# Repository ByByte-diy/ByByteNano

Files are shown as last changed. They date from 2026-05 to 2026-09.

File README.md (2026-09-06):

## **ByByte.DIY™ Nano** — Educational Robot Platform





Українська: [`README.uk`](README.uk.md)

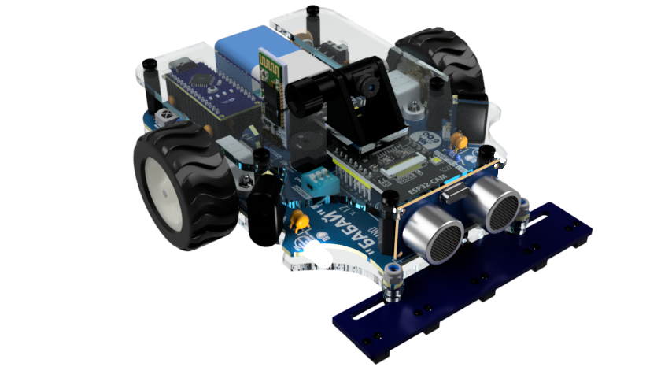
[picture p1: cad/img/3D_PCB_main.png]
ByByte Nano 3D View


**ByByte Nano** is a compact, beginner‑friendly educational robot platform from the ByByte series. It is designed for quick assembly, safe classroom use, and clear learning of robotics fundamentals: electronics, sensors, motor control, and embedded programming. Compared to the more advanced ByByte Mega, Nano focuses on simplicity and affordability while remaining extendable.

- Related project: see the larger sibling, ByByte Mega, for a more feature‑rich variant ([ByByte Mega](https://github.com/ByByte-diy/ByByteMega/blob/main/README.md)).

### Key Features
- Beginner‑friendly: simple assembly and clear layout
- Compact PCB: optimized footprint for classrooms and workshops
- Modular design: expansion headers for add‑ons and sensors
- Open hardware: schematic and PCB sources included
- Open firmware: works with common Arduino‑compatible toolchains

### Hardware Overview
- Main board: ByByte Nano PCB
- Microcontroller: Arduino‑compatible, Nano‑class form factor (ATmega328)
- Typical peripherals: motor drivers, line sensors, LEDs, power regulation
- Connectors: clearly labeled I/O and power headers for quick prototyping

View the full schematic:
- [`Schematic (PDF)`](hardware/schematics/SCH_ByByte_nano.pdf)

Board previews:
- [`Top PCB`](cad/img/2D_pcb_top.png)
- [`Bottom PCB`](cad/img/2D_pcb_bottom.png)

### Technical Specifications (high‑level)
- Power: 9V battery (PP3/“Krona”)
- CPU: Arduino Nano (ATmega328)
- Drive: micro N20 geared DC motors, approx. 600–1000 rpm
- Connectivity: USB (Arduino Nano), Bluetooth (HC‑02/HC‑05/HC‑06), optional Wi‑Fi via ESP32‑CAM

### Sensors and Interfaces
- 5 line sensors: line‑following capability
- Side optical analog sensors: maze navigation or obstacle avoidance
- Front distance sensor: ultrasonic range measurement
- Analog light sensor: ambient light intensity
- IR receiver: remote control via IR remote
- Bluetooth: smartphone/PC control support
- 2× WS2812 RGB LEDs: “headlights” visual feedback
- Passive buzzer: audible feedback

### Additional Peripherals
You can install an optional ESP32‑CAM module to stream video over Wi‑Fi. The ESP module can be programmed directly from the robot; set jumpers J1–J3 according to the schematic. You can also configure communication between ESP and the Arduino Nano to control the robot over Wi‑Fi.

### Mobility
Two side wheels provide differential (tank‑style) drive for precise motion control.

### Compatibility
Fully compatible with the Arduino IDE and a wide range of Arduino libraries, making it accessible for both beginners and experienced users.

### Educational Focus
Designed to help learners develop core programming and robotics skills through hands‑on projects:
- Integrate sensors and process data
- Program motion algorithms for obstacle avoidance, line following, and maze navigation
- Use visual and audio feedback to increase interactivity
- Understand controller‑based platforms and communication/control basics

### Assembly Notes
- Besides the PCB and ready‑made modules, a few discrete components are needed for assembly; the design targets easy soldering and widely available modules
- Before soldering the robot’s power modules, set the correct output voltages (5 V and 3.3 V) to protect sensitive electronics
- Before first power‑up, verify polarity; ideally power on without modules inserted and check all rails
- Start with power and logic tests, then connect motors and sensors
- Keep wires short and secure to reduce noise
- Finally, test the robot with example sketches before full use

### Bill of Materials

The complete parts list — **55 line items** with designators, quantities, values, and component photos — is in **[BOM.md](BOM.md)**.

At a glance, the build includes the ByByte Nano PCB, Arduino Nano, motor driver (DRV8834), N20 geared motors with wheels and mounts, 5-channel line tracker, ultrasonic sensor, Bluetooth module (HC-02/HC-05/HC-06), two DC-DC buck modules, ESP32-CAM (optional), and assorted passives, connectors, and mechanical hardware.

### Troubleshooting
- No power: check polarity and regulator output
- No USB upload: check board/port selection, drivers, and jumper positions J1–J3
- Motors not spinning: verify driver wiring and module health
- Sensors unresponsive: verify 5 V rail and wiring

### How to Contribute
Contributions are welcome:
1. Test and report issues by creating an issue
2. Help us fix problems and improve documentation
3. Optimize or enhance libraries by forking the repo and submitting a pull request

### License
This project is released under the license specified in [`LICENSE`](LICENSE.md).

This project is part of the ByByte.DIY™ open robotics ecosystem.

### Trademark notice:
**ByByte.DIY™** and the ByByte.DIY **logo** are trademarks of the project maintainers.

Copyright ⓒ 2026 ByByte.DIY™ contributors

<picture>
  <source media="(prefers-color-scheme: dark)" srcset="https://home.cern/wp-content/themes/cern/public/images/logo-white.svg">
  <source media="(prefers-color-scheme: light)" srcset="https://home.cern/wp-content/themes/cern/public/images/logo-blue.svg">
  CERN
</picture>

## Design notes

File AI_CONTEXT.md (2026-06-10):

# AI_CONTEXT.md — ByByte Nano (LLM / RAG Context)

> **Purpose:** structured technical context for the `ByByte-diy/ByByteNano` repository, intended for large language models, RAG pipelines, and coding agents.  
> **Project version:** 1.1.0 · **License:** CERN-OHL-S v2 · **Ecosystem:** ByByte.DIY™  
> **Last context sync:** 2026 (aligned with `README.md`, `BOM.md`, `hardware/`, `source/ByByte_nano.epro`)

---

## 1. Project Summary

**ByByte Nano** (also known as *Babai Nano* / *Бабай Nano* in Ukrainian materials) is a compact **open-hardware educational robotics platform**. It is designed for teaching electronics, sensors, motor control, and embedded programming in classrooms and workshops.

Key properties:
- beginner-friendly assembly (through-hole soldering + off-the-shelf modules);
- main controller: **Arduino Nano (ATmega328)**;
- differential drive (2× N20 geared motors);
- built-in sensor set: line tracking, distance, ambient light, IR remote;
- optional side IR sensors (mainly for maze navigation — may be omitted if not needed);
- optional **ESP32-CAM** (Wi-Fi / video);
- Bluetooth (**HC-02 / HC-05 / HC-06**);
- 2.54 mm expansion headers.

**Related platform:** [ByByte Mega](https://github.com/ByByte-diy/ByByteMega) — a more feature-rich sibling in the same product line.

**What this repository contains today:** hardware documentation, BOM, schematic, Gerber files, CAD images, and an EasyEDA project. **Firmware and example sketches are not included** in the repo (mentioned in README as external / planned).

---

## 2. Repository Map (Key Files)

| Path | Description |
|---|---|
| `README.md` / `README.uk.md` | Project overview (English / Ukrainian) |
| `BOM.md` | Full bill of materials (57 line items + consumables + tools) |
| `AI_CONTEXT.md` | This file — AI / RAG context |
| `LICENSE.md` / `LICENSE-CERN.txt` | CERN-OHL-S v2 |
| `hardware/schematics/SCH_ByByte_nano.pdf` | Schematic (PDF) |
| `hardware/pcb/ByByte_nano_pcb.pdf` | PCB layout preview (PDF) |
| `hardware/pcb/Gerber_pcb_ByByte_nano.zip` | Gerber package for PCB fabrication |
| `hardware/bom/BOM_ByByte_Nano.xlsx` | BOM spreadsheet |
| `hardware/bom/img/` | Component photos / renders |
| `cad/img/3D_PCB_main.png` | 3D board render |
| `cad/img/2D_pcb_top.png` | Top view (2D) — note lowercase `pcb` in filename |
| `cad/img/2D_pcb_bottom.png` | Bottom view (2D) |
| `source/ByByte_nano.epro` | EasyEDA project (ZIP archive: schematic + PCB) |

---

## 3. System Architecture (Functional Blocks)

On the main schematic (`main` sheet in EasyEDA), the board is organized into these logical blocks:

| Block (schematic label) | Function | Key components |
|---|---|---|
| **POWER SUPPLY** | 9V input, regulation | `BAT1`, `D4`, `D5`, `F1`, `U3`, `U4`, `C1–C5`, `L1`, `L2` |
| **CONTROLLER** | Main MCU | `U1` Arduino Nano |
| **MOTOR DRIVER** | N20 motor control | `U2` DRV8833, `M1`, `M2` |
| **ULTRASONIC** | Front ranging | `U5` HC-SR04 |
| **IR LINE TRACKER** | 5-channel line sensing | `U6` TRCT5000 5-way module |
| **SIDES SENSORS** *(optional)* | Side analog IR — maze navigation | `D1`, `D2`, `Q2`, `Q3`, `U9` LM358 |
| **IR SENSOR** | IR remote receiver | `U7` VS1838B |
| **LIGHT SENSOR** | Ambient light | `LDR1` + divider |
| **LEDS** | Status / headlights | `LED1` (green), `LED2`, `LED3` WS2812 |
| **BUZZER** | Audio feedback | `BUZZER1` |
| **BLUETOOTH** | Wireless control | `BLUETOOTH1` |
| **ESP32 Camera module** | Wi-Fi / camera (optional) | `U8` ESP32-CAM |

The EasyEDA project also includes a separate **`LineTracker_SCH`** schematic and **`LIneTracker_PCB`** — a reference line-tracker design. The assembled robot uses the ready-made module `U6` instead.

---

## 4. Power System

| Parameter | Value |
|---|---|
| Source | 9V Li-ion rechargeable battery, PP3 / “Krona” form factor (`BAT1` + BH9VPC holder) |
| Input protection | `F1` fuse (optional), ferrite beads `L1`, `L2` |
| Diodes | `D4` 1N5822, `D5` 1N5817 (Schottky) |
| Regulators | 2× DC-DC buck modules `U3`, `U4`: **MH-MINI-361** or **HW-613** (EasyEDA schematic lists MH-MINI-360) |
| Output rails | **+5 V** and **+3.3 V** (adjusted via trim pots on modules **before soldering!**) |
| Power switch | `SW1` slider switch |
| Indicator | `LED1` green — power (labeled PWR on schematic) |

**Critical assembly step:** before soldering `U3`/`U4`, use a multimeter to set **5.0 V** and **3.3 V**. On first power-up, test without plug-in modules installed; verify polarity and all rails.

---

## 5. Controller and Connectivity

### 5.1 Arduino Nano (`U1`)
- **MCU:** ATmega328, Arduino Nano form factor (v3, “old” footprint per BOM);
- mounted on **2× 1×15 female headers** (`U1 holder`, PBS-15);
- firmware upload via **USB** (Mini-B / Micro-B / Type-C depending on Nano revision);
- toolchain: **Arduino IDE**, standard Arduino libraries.

### 5.2 Bluetooth (`BLUETOOTH1`)
- Supported modules: **HC-02, HC-05, HC-06** (BOM lists HC-06);
- UART interface to Nano;
- control from smartphone or PC.

### 5.3 ESP32-CAM (`U8`, optional)
- Module with 120° camera;
- socket: **2× 1×8 female headers** (`U8 holder`);
- jumpers **J1, J2, J3** (pins from strip `H1,H2,H5,H6,J1,J2,J3`) route ESP programming / UART (see `SCH_ByByte_nano.pdf`);
- UART link to Arduino Nano possible for Wi-Fi-based control.

### 5.4 User inputs
- `KEY1`, `KEY2` — 6 mm tactile buttons;
- `SW1` — power slider switch.

---

## 6. Drive and Mechanics

| Component | Qty | Description |
|---|:---:|---|
| `M1`, `M2` | 2 | N20 DC geared motor, 6V, 500–1000 rpm |
| `Mount`, `Mount1` | 2 | N20 ABS motor bracket |
| `Wheel` | 2 | N20 wheel, 44 mm, 3 mm shaft |
| `Ball wheel` | 2 | Rear caster / ball support |
| `U2` | 1 | **DRV8833** dual H-bridge motor driver |
| `U2 holder` | 2 | 1×6 female header PBS-06 |

**Fasteners:** M2×8 screws (3), M3×12 screws (4), HTP-320 standoffs 20 mm (2), HTP-305 standoffs 5 mm (2), DIN985 lock nuts M2 (3), M3 (2).

**Kinematics:** differential (tank-style) drive — two drive wheels plus ball casters.

---

## 7. Sensors and Indicators

| Designator | Part | Function |
|---|---|---|
| `U6` | TRCT5000 5-way | **5 line sensors** (line following) |
| `U5` | HC-SR04 | **Ultrasonic** front distance |
| `LDR1` | ~10k LDR | **Ambient light** (analog) |
| `D1`, `D2` + `Q2`, `Q3` + `U9` | IR LED + phototransistor + LM358 | **Side optical sensors** *(optional)* — primarily for **maze navigation**; skip if maze mode is not planned |
| `U7` | VS1838B | **IR remote receiver** |
| `LED2`, `LED3` | WS2812B-TH 5 mm | **Addressable RGB headlights** |
| `LED1` | Green 3 mm LED | Power indicator |
| `BUZZER1` | Passive 5V buzzer | Audio feedback |

**Side IR sensors (optional):** The **SIDES SENSORS** block (`D1`, `D2`, `Q2`, `Q3`, `U9` LM358, DIP-8 socket, and related passives) is **not required** for basic operation. It is intended mainly for **maze navigation** (wall detection on left/right). If maze projects are not planned, these parts **may be left unpopulated** — line following, obstacle avoidance with the front ultrasonic sensor, Bluetooth/IR control, and other features still work without them.

**Assembly note (if installing side IR):** `D1`/`D2` IR LEDs should be covered with **black 8 mm heat-shrink tubing** (see Consumables in `BOM.md`).

### Optional hardware summary

| Feature | Parts | When to skip |
|---|---|---|
| Fuse | `F1` | If extra input protection is not desired |
| Side IR / maze sensors | `D1`, `D2`, `Q2`, `Q3`, `U9`, U9 socket | No maze navigation planned |
| ESP32-CAM | `U8`, `U8 holder` | No Wi-Fi / video needed |
| Bluetooth | `BLUETOOTH1` | Wired/USB control only |

---

## 8. Full BOM (57 Line Items)

> Source of truth: `BOM.md`. Text copy below for RAG indexing (no images).

### 8.1 PCB, power, protection (1–10)
1. `BAT1` — 9V battery holder BH9VPC ×1  
2. Li-ion Battery — 9V PP3 BAT-6F22 ×1  
3. `C1,C4,C17` — 470µF 16V electrolytic ×2  
4. `C3,C5` — 470µF 6.3V electrolytic ×3  
5. `D4` — 1N5822 Schottky ×1  
6. `D5` — 1N5817 Schottky ×1  
7. `F1` — TRF250-1000 fuse (optional) ×1  
8. `L1,L2` — ferrite bead R6H-3.0T ×2  
9. `U3,U4` — DC-DC buck MH-MINI-361 / HW-613 ×2  
10. PCB — ByByte Nano main board ×1  

### 8.2 Passive components (11–20)
11. `C2,C6,C7,C9,C11,C12,C13,C14,C18` — 1µF 50V ceramic ×9  
12. `C8,C10,C19` — 0.1µF 50V ceramic ×3  
13. `C15,C16` — 10nF 50V ceramic ×2  
14. `R1,R2` — 1kΩ 1/8W ×2  
15. `R3,R6,R9,R10,R14` — 10kΩ 1/8W ×5  
16. `R4,R5` — 39Ω 1/4W ×2  
17. `R7,R8` — 1.8kΩ 1/8W ×2  
18. `R11,R12` — 100kΩ 1/8W ×2  
19. `R13` — 330Ω 1/8W ×1  
20. `R15` — 100Ω 1/8W ×1  

### 8.3 Semiconductors (21–29)

> **Optional block — side IR / maze sensors:** items 21, 26, 28, 29 (`D1`, `D2`, `Q2`, `Q3`, `U9`, socket) may be omitted if maze navigation is not needed.

21. `D1,D2` — IR LED SFH4545 ×2 *(optional — side sensors)*  
22. `D3` — 1N4148 ×1  
23. `LED1` — green 3 mm FYL-3004GD ×1  
24. `LED2,LED3` — WS2812B-TH ×2  
25. `Q1` — NPN 9014-C ×1  
26. `Q2,Q3` — IR phototransistor TEFT4300 ×2 *(optional — side sensors)*  
27. `Q4` — MOSFET BS170 ×1  
28. `U9` — op-amp LM358AP ×1 *(optional — side sensors)*  
29. `U9 socket` — DIP-8 GOLD-8P ×1 *(optional — side sensors)*  

### 8.4 Modules and controllers (30–38)
30. `BLUETOOTH1` — HC-06 (HC-02/05/06 compatible) ×1  
31. `BUZZER1` — passive 5V buzzer ×1  
32. `LDR1` — 10k photoresistor ×1  
33. `U1` — Arduino Nano ATmega328 ×1  
34. `U2` — DRV8833 motor driver ×1  
35. `U5` — HC-SR04 ultrasonic sensor ×1  
36. `U6` — TRCT5000 5-channel line tracker ×1  
37. `U7` — VS1838B IR receiver ×1  
38. `U8` — ESP32-CAM 120° ×1  

### 8.5 Connectors and switches (39–47)
39. `H1,H2,H5,H6,J1,J2,J3` — 1×40 pin header ZL201-40G ×1 (cut to length)  
40. `H3,H4` — 2×1 female header 90° ZL263-2SG ×2  
41. `XP3,XP4` — 1×40 pin header 90° ZL211-40KG-S ×1  
42. `KEY1,KEY2` — 6 mm tactile switch ×2  
43. `SW1` — slider switch SS-12D ×1  
44. `U1 holder` — 1×15 female header PBS-15 ×2  
45. `U8 holder` — 1×8 female header ZL262-8SG ×2  
46. `U6 holder` — 1×7 female header PBS-07R ×1  
47. `U2 holder` — 1×6 female header PBS-06 ×2  

### 8.6 Mechanics (48–57)
48. `M1,M2` — N20 motor ×2  
49. `Mount,Mount1` — N20 mount ×2  
50. `Ball wheel` ×2  
51. `Wheel` N20 44 mm ×2  
52. M2×8 screw ×3  
53. M3×12 screw ×4  
54. HTP-320 standoff 20 mm ×2  
55. HTP-305 standoff 5 mm ×2  
56. M3 DIN985 lock nut ×2  
57. M2 DIN985 lock nut ×3  

### 8.7 Consumables (not counted in line items)
- Solder wire 0.8–1.0 mm (Sn60/Pb40)  
- Flux paste (optional)  
- Isopropyl alcohol 99% (optional)  
- Black 8 mm heat-shrink tubing *(only if side IR LEDs `D1`/`D2` are installed)*  

### 8.8 Required tools
- Soldering iron 25–60 W (temperature-controlled)  
- Side / flush cutters  
- Multimeter  
- Small Phillips screwdriver  
- USB cable  
- PC with Arduino IDE  

---

## 9. Connectors and Expansion

- **2.54 mm headers:** horizontal (`H1–H6`, `J1–J3`) and 90° (`XP3`, `XP4`) for modules and prototyping;
- **Socketed modules:** Nano, ESP32-CAM, DRV8833, line tracker — removable;
- **Expansion:** free Arduino pins routed to headers (pinout in `SCH_ByByte_nano.pdf`).

---

## 10. PCB Manufacturing

| Artifact | File |
|---|---|
| Gerber + drill | `hardware/pcb/Gerber_pcb_ByByte_nano.zip` |
| PDF preview | `hardware/pcb/ByByte_nano_pcb.pdf` |
| Editable source | `source/ByByte_nano.epro` (EasyEDA) |
| PCB names in project | `PCB1` (main), `Board1_main` in BOM |

Under CERN-OHL-S v2, products made from this design should **keep the Source Location visible on PCB silkscreen** where practicable.

---

## 11. Recommended Assembly Order

1. Solder small passives and semiconductors on the main PCB (skip `D1`, `D2`, `Q2`, `Q3`, `U9` and socket if side IR / maze sensors are not needed).  
2. Solder connectors, buttons, and power switch.  
3. **Trim `U3`/`U4` to 5 V and 3.3 V** (modules not yet installed).  
4. Solder DC-DC modules; verify rails.  
5. Install `U9` socket, LM358, and plug-in modules (`U2`, `U5`, `U6`, `BLUETOOTH1`, `BUZZER1`).  
6. Insert Arduino Nano and ESP32-CAM (optional).  
7. Assemble mechanics: motors, wheels, standoffs.  
8. Check battery polarity, power on, test with example sketches.  

---

## 12. Software / Firmware Context

- **Target platform:** Arduino IDE, ATmega328 on Arduino Nano.  
- **Typical libraries:** `Serial` / `SoftwareSerial` for Bluetooth, `NewPing` or custom code for HC-SR04, `Adafruit_NeoPixel` or FastLED for WS2812, `IRremote` for VS1838B.  
- **ESP32-CAM:** flashed separately (Arduino IDE / ESP-IDF); J1–J3 control UART routing.  
- **This repository does not contain** a `firmware/` folder or `.ino` sketch files — hardware only.

---

## 13. Educational Use Cases

- line following (5 IR channels);  
- obstacle avoidance (front ultrasonic);  
- maze navigation (optional side IR sensors + ultrasonic);  
- IR remote or Bluetooth control;  
- visual and audio feedback (WS2812, buzzer);  
- optional video streaming (ESP32-CAM);  
- core concepts: power rails, PWM, ADC, UART, I²C/SPI (depending on wiring).

---

## 14. Troubleshooting Knowledge Base

| Symptom | Likely causes | Actions |
|---|---|---|
| No power | Polarity, `SW1`, dead battery, `F1` | Measure +9V, 5V, 3.3V with multimeter |
| USB upload fails | Wrong board/port, drivers, J1–J3 routing | Check ESP jumpers, cable, CH340/FTDI driver |
| Motors not spinning | `U2` DRV8833, wiring, PWM pins | Verify driver supply and DIR/PWM signals |
| Sensors unresponsive | Missing 5V, bad socket contact | Check 5V rail, analog/digital pin mapping |
| WS2812 not lighting | Wrong GPIO, 5V level, library config | Verify data pin, library, color order |
| Bluetooth won't connect | RX/TX swapped, baud mismatch | Try 9600/115200; HC-05 AT mode if needed |

---

## 15. Known Documentation Discrepancies (for AI grounding)

| Topic | README | BOM / schematic (preferred) |
|---|---|---|
| Line item count | 55 | **57** (`BOM.md` Summary) |
| Motor driver | DRV8834 | **DRV8833** |
| Ultrasonic sensor | HC-SR05 (legacy) | **HC-SR04** |
| Motor speed | 600–1000 rpm | **500–1000 rpm** |
| DC-DC in epro | MH-MINI-360 | BOM: **MH-MINI-361** / HW-613 |
| 2D PCB image path | `2D_PCB_*.png` (old) | **`2D_pcb_*.png`** (case-sensitive on GitHub) |

**Priority when answering users:** `BOM.md` → `SCH_ByByte_nano.pdf` → `source/ByByte_nano.epro`.

---

## 16. Retrieval Keywords

```
ByByte, ByByte Nano, Babai Nano, Arduino Nano, ATmega328, educational robot,
open hardware, CERN-OHL, EasyEDA, DRV8833, HC-SR04, HC-06, ESP32-CAM,
WS2812, line follower, TRCT5000, N20 motor, 9V battery, PP3, Krona,
ultrasonic sensor, line sensor, Bluetooth robot, DIY robot, robotics kit,
BOM, schematic, motor driver, IR sensor, maze robot, classroom robot
```

---

## 17. Trademark and License

- **ByByte.DIY™** and the ByByte.DIY logo are trademarks of the project maintainers.  
- License: **CERN Open Hardware Licence version 2 — Strongly Reciprocal (CERN-OHL-S v2)**.  
- Copyright © 2026 ByByte.DIY™ contributors.

---

*End of AI_CONTEXT.md*

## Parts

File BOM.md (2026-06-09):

# Bill of Materials (BOM)

**ByByte Nano** — main board (`Board1_main`)

Full component list for robot assembly. Tables are grouped by part type.

---

## PCB, power & protection

| # | Designator | Qty | Description | Value / model | Image |
|:--:|---|:-----:|---|---|:-----:|
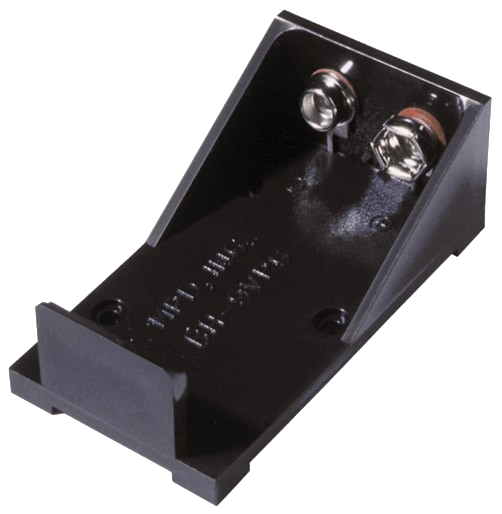
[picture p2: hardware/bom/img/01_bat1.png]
Battery holder
| 1 | `BAT1` | 1 | Battery holder | BH9VPC |  |
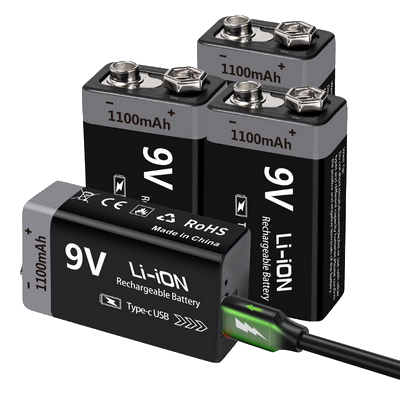
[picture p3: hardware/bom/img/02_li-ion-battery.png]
9V Li-ion rechargeable battery
| 2 | `Li-ion Battery` | 1 | 9V Li-ion rechargeable battery (PP3 / “Krona” form factor) | BAT-6F22 |  |
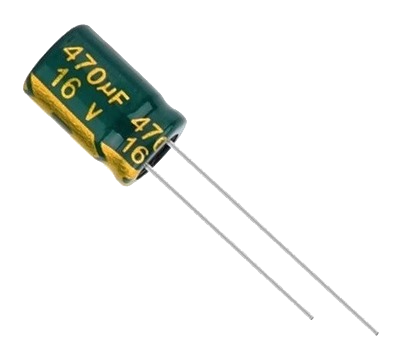
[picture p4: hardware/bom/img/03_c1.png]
| 3 | `C1,C4,C17` | 2 | Electrolytic capacitor, low ESR | 470uF 16v |  |
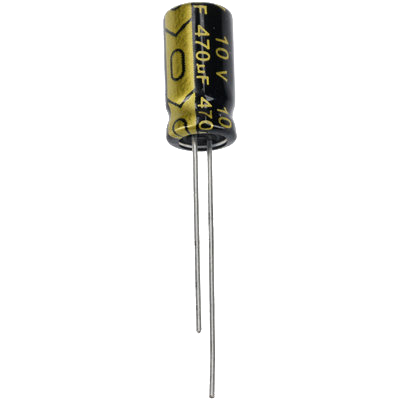
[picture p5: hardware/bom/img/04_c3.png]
| 4 | `C3,C5` | 3 | Electrolytic capacitor, low ESR | 470uF 6.3v |  |
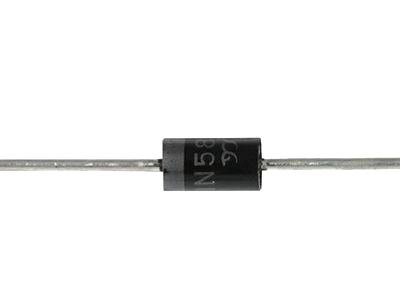
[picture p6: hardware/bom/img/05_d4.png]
| 5 | `D4` | 1 | Schottky diode | 1N5822 |  |
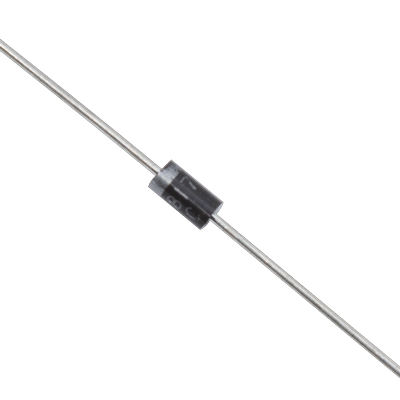
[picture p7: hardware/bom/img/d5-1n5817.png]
| 6 | `D5` | 1 | Schottky diode | 1N5817 |  |
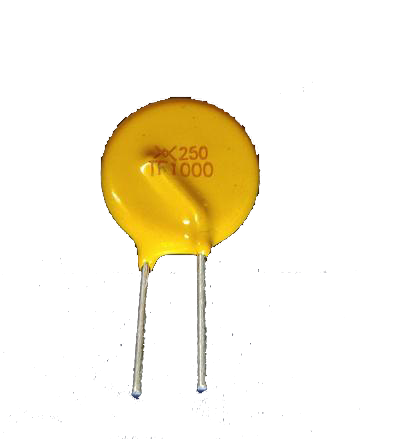
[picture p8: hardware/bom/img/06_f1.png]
Fuse (optional)
| 7 | `F1` | 1 | Fuse (optional) | TRF250-1000 (optional) |  |
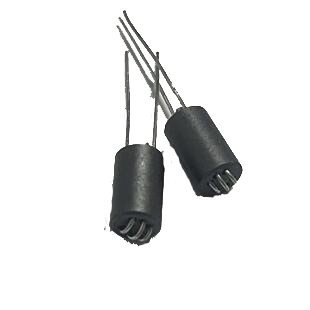
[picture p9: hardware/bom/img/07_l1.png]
Leaded EMI ferrite bead
| 8 | `L1,L2` | 2 | Leaded EMI ferrite bead | R6H-3.0T |  |
| 9 | `U3,U4` | 2 | DC-DC buck module | MH-MINI-361 (or HW-613) | DC-DC buck module |
| 10 | `pcb` | 1 | Main ByByte nano board | PCB | Main ByByte nano board |

## Passive components

| # | Designator | Qty | Description | Value / model | Image |
|:--:|---|:-----:|---|---|:-----:|
| 11 | `C2,C6,C7,C9,C11,C12,C13,C14,C18` | 9 | Ceramic capacitor | 1uF 50v | Ceramic capacitor |
| 12 | `C8,C10,C19` | 3 | Ceramic capacitor | 0.1uF 50v | Ceramic capacitor (100 nF) |
| 13 | `C15,C16` | 2 | Ceramic capacitor | 10nF 50v | Ceramic capacitor |
| 14 | `R1,R2` | 2 | 1/8 W resistor | 1kΩ | 1/8 W resistor |
| 15 | `R3,R6,R9,R10,R14` | 5 | 1/8 W resistor | 10kΩ | 1/8 W resistor |
| 16 | `R4,R5` | 2 | 1/4 W resistor | 39Ω | 1/2 W resistor |
| 17 | `R7,R8` | 2 | 1/8 W resistor | 1.8kΩ | 1/8 W resistor |
| 18 | `R11,R12` | 2 | 1/8 W resistor | 100kΩ | 1/8 W resistor |
| 19 | `R13` | 1 | 1/8 W resistor | 330Ω | 1/8 W resistor |
| 20 | `R15` | 1 | 1/8 W resistor | 100Ω | 1/8 W resistor |

## Semiconductors & diodes

| # | Designator | Qty | Description | Value / model | Image |
|:--:|---|:-----:|---|---|:-----:|
| 21 | `D1,D2` | 2 | IR LED | SFH4545 | IR LED |
| 22 | `D3` | 1 | Diode | 1N4148 | Diode |
| 23 | `LED1` | 1 | Green LED 3 mm | FYL-3004GD | Green LED 3 mm |
| 24 | `LED2,LED3` | 2 | 5 mm addressable RGB LED (WS2812) | WS2812B-TH | 5 mm addressable RGB LED (WS2812) |
| 25 | `Q1` | 1 | NPN transistor | 9014-C | NPN transistor |
| 26 | `Q2,Q3` | 2 | IR phototransistor | TEFT4300 | IR phototransistor |
| 27 | `Q4` | 1 | HEXFET / MOSFET transistor | BS170 | HEXFET / MOSFET transistor |
| 28 | `U9` | 1 | Operational amplifier | LM358AP | Operational amplifier |
| 29 | `U9` | 1 | DIP-8 IC socket | GOLD-8P | DIP-8 IC socket |

## Modules & controllers

| # | Designator | Qty | Description | Value / model | Image |
|:--:|---|:-----:|---|---|:-----:|
| 30 | `BLUETOOTH1` | 1 | Bluetooth module (HC-02 / HC-05 / HC-06) | HC-06 | Bluetooth module |
| 31 | `BUZZER1` | 1 | Passive buzzer 5V | buzzer-12X9 | Passive buzzer 5V |
| 32 | `LDR1` | 1 | Photo-resistor (LDR) | 10k | Photo-resistor (LDR) |
| 33 | `U1` | 1 | Arduino Nano (ATmega328) | Arduino nano v3 (old) | Arduino Nano (ATmega328) |
| 34 | `U2` | 1 | Motor driver module | DRV8833 | Motor driver module |
| 35 | `U5` | 1 | Ultrasonic distance sensor | HC-SR04 | Ultrasonic distance sensor |
| 36 | `U6` | 1 | Line tracker module (5 channels) | TRCT5000 5way module | Line tracker module (5 channels) |
| 37 | `U7` | 1 | IR receiver IC | VS1838B | IR receiver IC |
| 38 | `U8` | 1 | ESP32-CAM module with 120° camera | ESP32-CAM | ESP32-CAM module with 120° camera |

## Connectors, switches & buttons

| # | Designator | Qty | Description | Value / model | Image |
|:--:|---|:-----:|---|---|:-----:|
| 39 | `H1,H2,H5,H6,J1,J2,J3` | 1 | 1×40 pin header, 2.54 mm pitch | ZL201-40G | 1×40 pin header, 2.54 mm pitch |
| 40 | `H3,H4` | 2 | 2×1 female header, 2.54 mm, 90° | ZL263-2SG | 2×1 female header, 2.54 mm, 90° |
| 41 | `XP3,XP4` | 1 | 1×40 pin header, 2.54 mm pitch, 90° | ZL211-40KG-S | 1×40 pin header, 2.54 mm pitch, 90° |
| 42 | `KEY1,KEY2` | 2 | 6 mm tactile button, 4 pins | 1301.9301 | 6 mm tactile button, 4 pins |
| 43 | `SW1` | 1 | Slider switch, 90° | SS-12D | Slider switch, 90° |
| 44 | `U1 holder` | 2 | 1×15 female header, 2.54 mm (for Nano) | PBS-15 | 1×15 female header |
| 45 | `U8 holder` | 2 | 1×8 female header, 2.54 mm (for ESP32-CAM) | ZL262-8SG | 1×8 female header, 2.54 mm (for ESP32-CAM) |
| 46 | `U6 holder` | 1 | 1×7 female header, 2.54 mm (for line trackers) | PBS-07R | 1×7 female header, 2.54 mm |
| 47 | `U2 holder` | 2 | 1×6 female header, 2.54 mm | PBS-06 | 1×6 female header, 2.54 mm |

## Mechanics & drive

| # | Designator | Qty | Description | Value / model | Image |
|:--:|---|:-----:|---|---|:-----:|
| 48 | `M1,M2` | 2 | DC geared motor N20, 6V | N20 motor 500-1000 rpm | DC geared motor N20, 6V |
| 49 | `Mount,Mount1` | 2 | N20 ABS motor mount with screw | N20 mount | N20 ABS motor mount with screw |
| 50 | `Ball wheel` | 2 | N20 mini caster / ball wheel | Ball wheel mini | N20 mini caster / ball wheel |
| 51 | `Wheel` | 2 | N20 wheel, 44 mm, 3 mm shaft | N20 44mm | N20 wheel, 44 mm, 3 mm shaft |
| 52 | `M2 x 8mm screw` | 3 | M2 screw 8mm length | M2x8mm | M2 screw 8mm length |
| 53 | `M3 x 12mm screw` | 4 | M3 screw 12mm length | M3x12mm | M3 screw 12mm length |
| 54 | `HTP-320` | 2 | Plastic standoff 20mm M3 double-sided | HTP-320 | Plastic standoff 20mm M3 double-sided |
| 55 | `HTP-305` | 2 | Plastic standoff 5mm M3 double-sided | HTP-305 | Plastic standoff 5mm M3 double-sided |
| 56 | `M3 DIN 985` | 2 | M3 self-locking nut | M3 DIN985 | M3 self-locking nut |
| 57 | `M2 DIN 985` | 3 | M2 self-locking nut | M2 DIN985 | M2 self-locking nut |

## Consumables

Materials used during assembly; not included in the robot BOM line count above.

| # | Qty | Description | Notes | Image |
|:--:|:-----:|---|---|---|
| 1 | 1 | Solder wire, 0.8–1.0 mm | Sn60/Pb40 (Cynel recommended); for through-hole components and headers | Solder wire |
| 2 | 1 | Flux paste or rosin flux | (Optional) makes soldering easier on pads and pin headers | Flux paste or rosin flux |
| 3 | 1 | Isopropyl alcohol (IPA), 99% | (Optional) flux residue cleaning after soldering | Isopropyl alcohol (IPA), 99% |
| 4 | 1 | Heat shrink tubing 8mm diameter **BLACK!** | for isolating IR LEDs | Heat shrink tubing |

## Required tools

| # | Tool | Purpose | Image |
|:--:|---|---|---|
| 1 | Soldering iron (25–60 W, temperature-controlled) | Soldering passives, semiconductors, connectors, and modules | Soldering iron |
| 2 | Side / flush cutters | Trimming component leads; cutting pin headers to length | Side / flush cutters |
| 3 | Multimeter | Setting DC-DC outputs to 5 V and 3.3 V; polarity and rail checks before first power-up | Multimeter |
| 4 | Small Phillips screwdriver | M2/M3 assembly; adjusting DC-DC module trim pots | Small Phillips screwdriver |
| 5 | USB cable (Mini-B or Micro-B or Type-C, per Nano revision) | Uploading firmware to Arduino Nano | USB cable |
| 6 | PC with Arduino IDE | Programming and testing | PC with Arduino IDE |

**Optional:** helping hands / PCB holder, magnifying lamp.

---

## Summary

| Parameter | Value |
|---|---|
| Unique line items | 57 |
| Optional parts | F1 (fuse) |
| Bluetooth | HC-02 / HC-05 / HC-06 |
| DC-DC modules | MH-MINI-361 or HW-613 (recommended) |
| Controller | Arduino Nano v3 (ATmega328) |

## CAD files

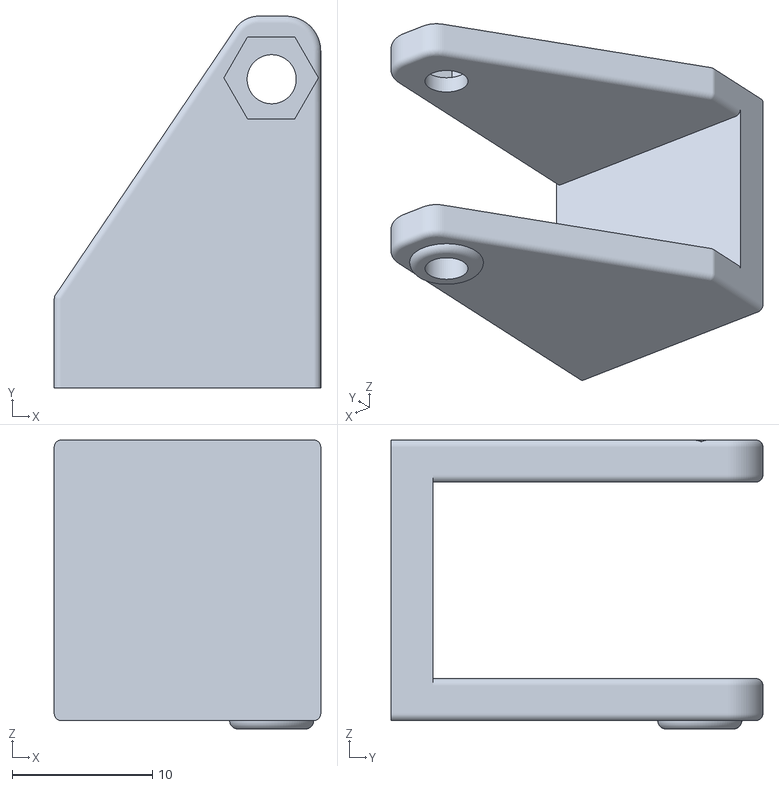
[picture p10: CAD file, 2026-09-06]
cad/models/camera-mount/main-rail.stl
19.0 x 26.5 x 20.6

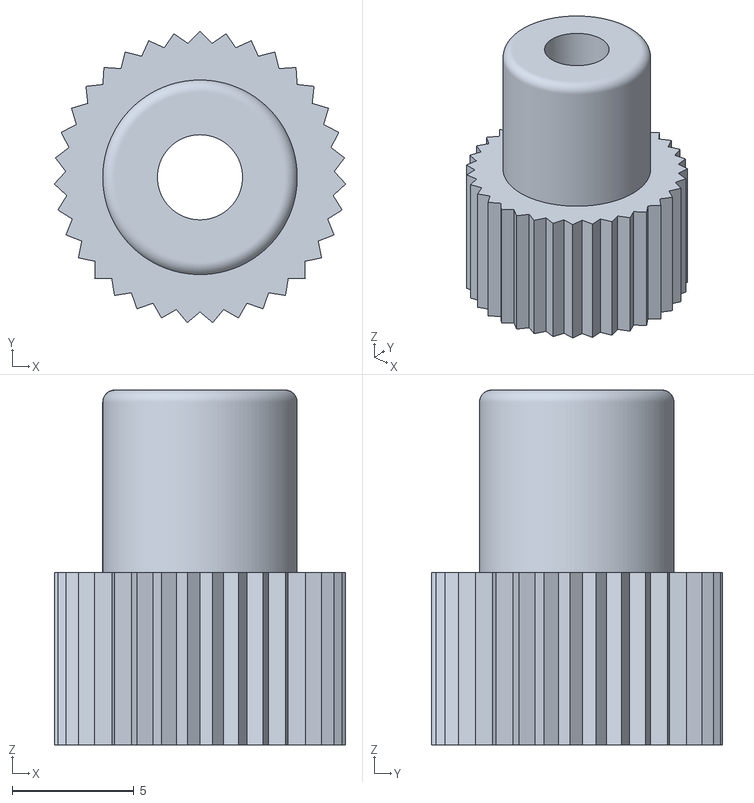
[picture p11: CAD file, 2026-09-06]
cad/models/camera-mount/clamp.stl
12.0 x 12.0 x 14.6

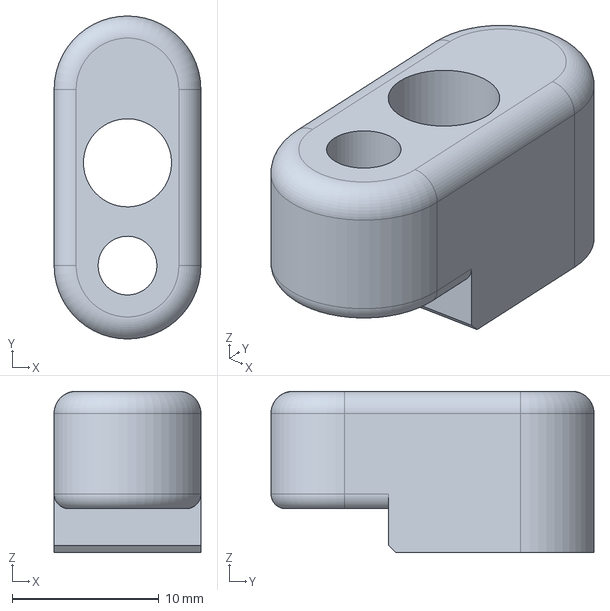
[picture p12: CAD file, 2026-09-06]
cad/models/ir-side-sensors/side-sensor-cover.step
10.0 x 22.0 x 11.0 mm

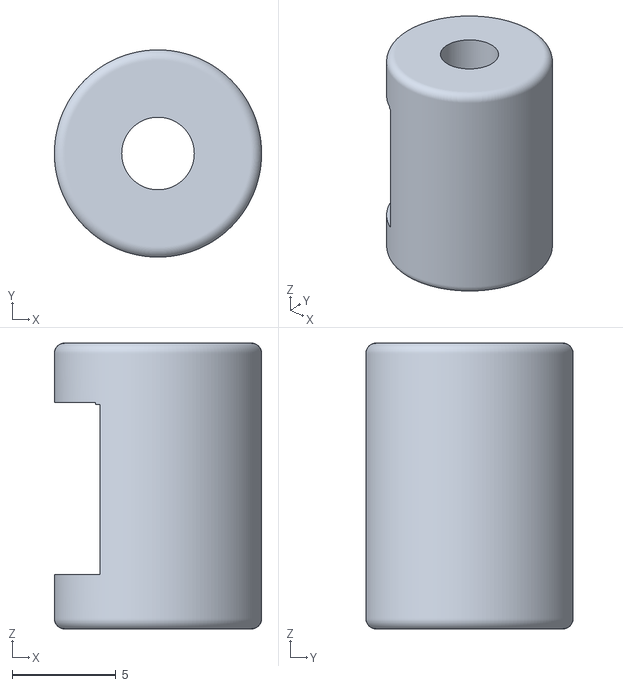
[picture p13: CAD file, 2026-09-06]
cad/models/camera-mount/camera-holder.stl
10.0 x 10.00 x 13.8

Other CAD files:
cad/models/ir-side-sensors/side-sensor-cover.stl

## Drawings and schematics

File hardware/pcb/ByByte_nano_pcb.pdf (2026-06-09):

+

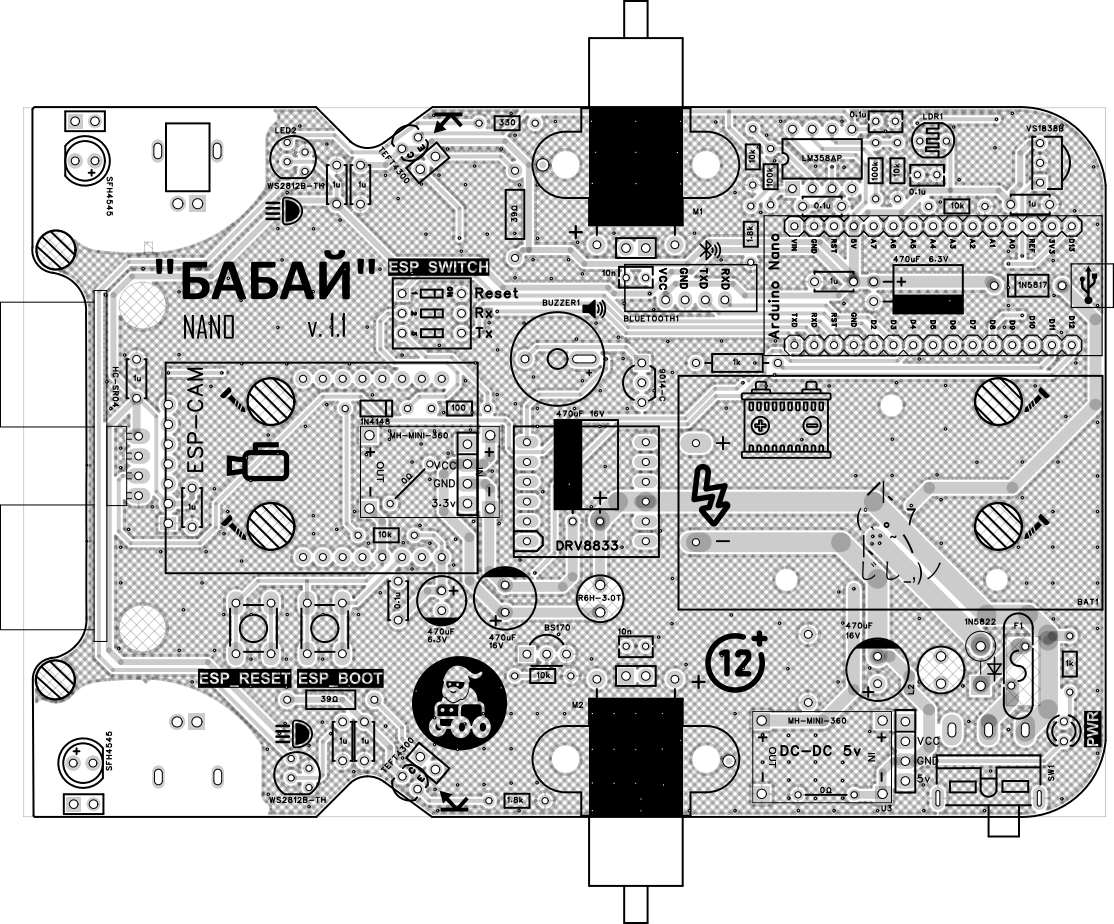
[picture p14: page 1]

## Motor Right IN1 ~D5

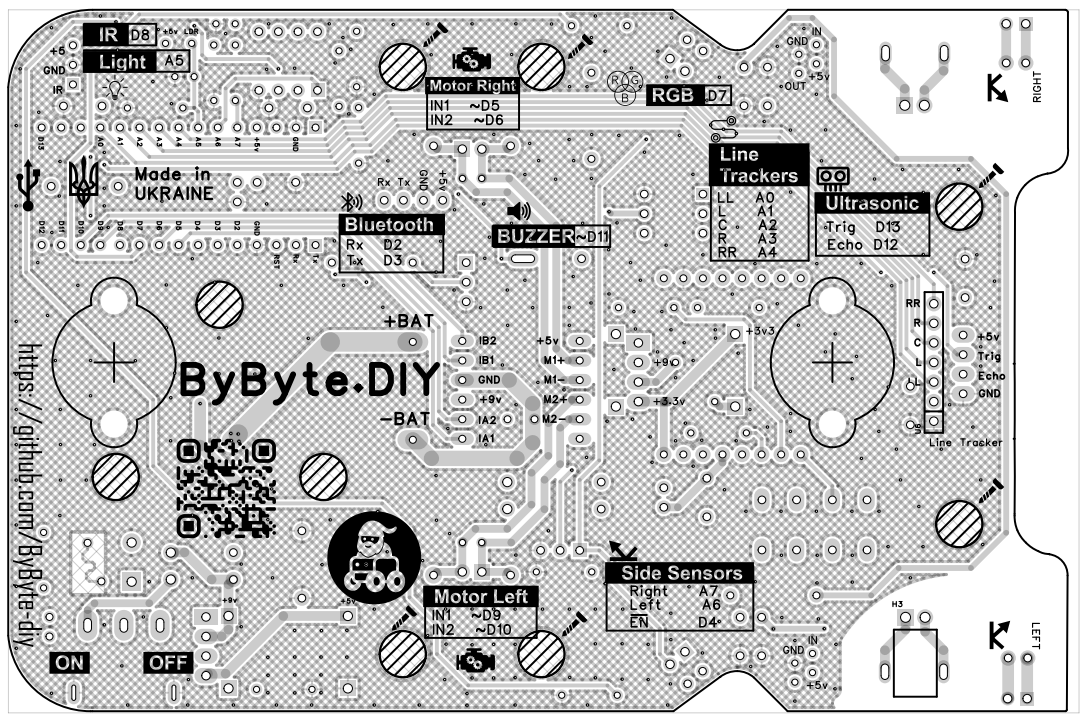
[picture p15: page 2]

https://github.com/ByByte-diy

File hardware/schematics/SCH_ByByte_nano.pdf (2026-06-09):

# BUZZER

LEDS | BLUETOOTH

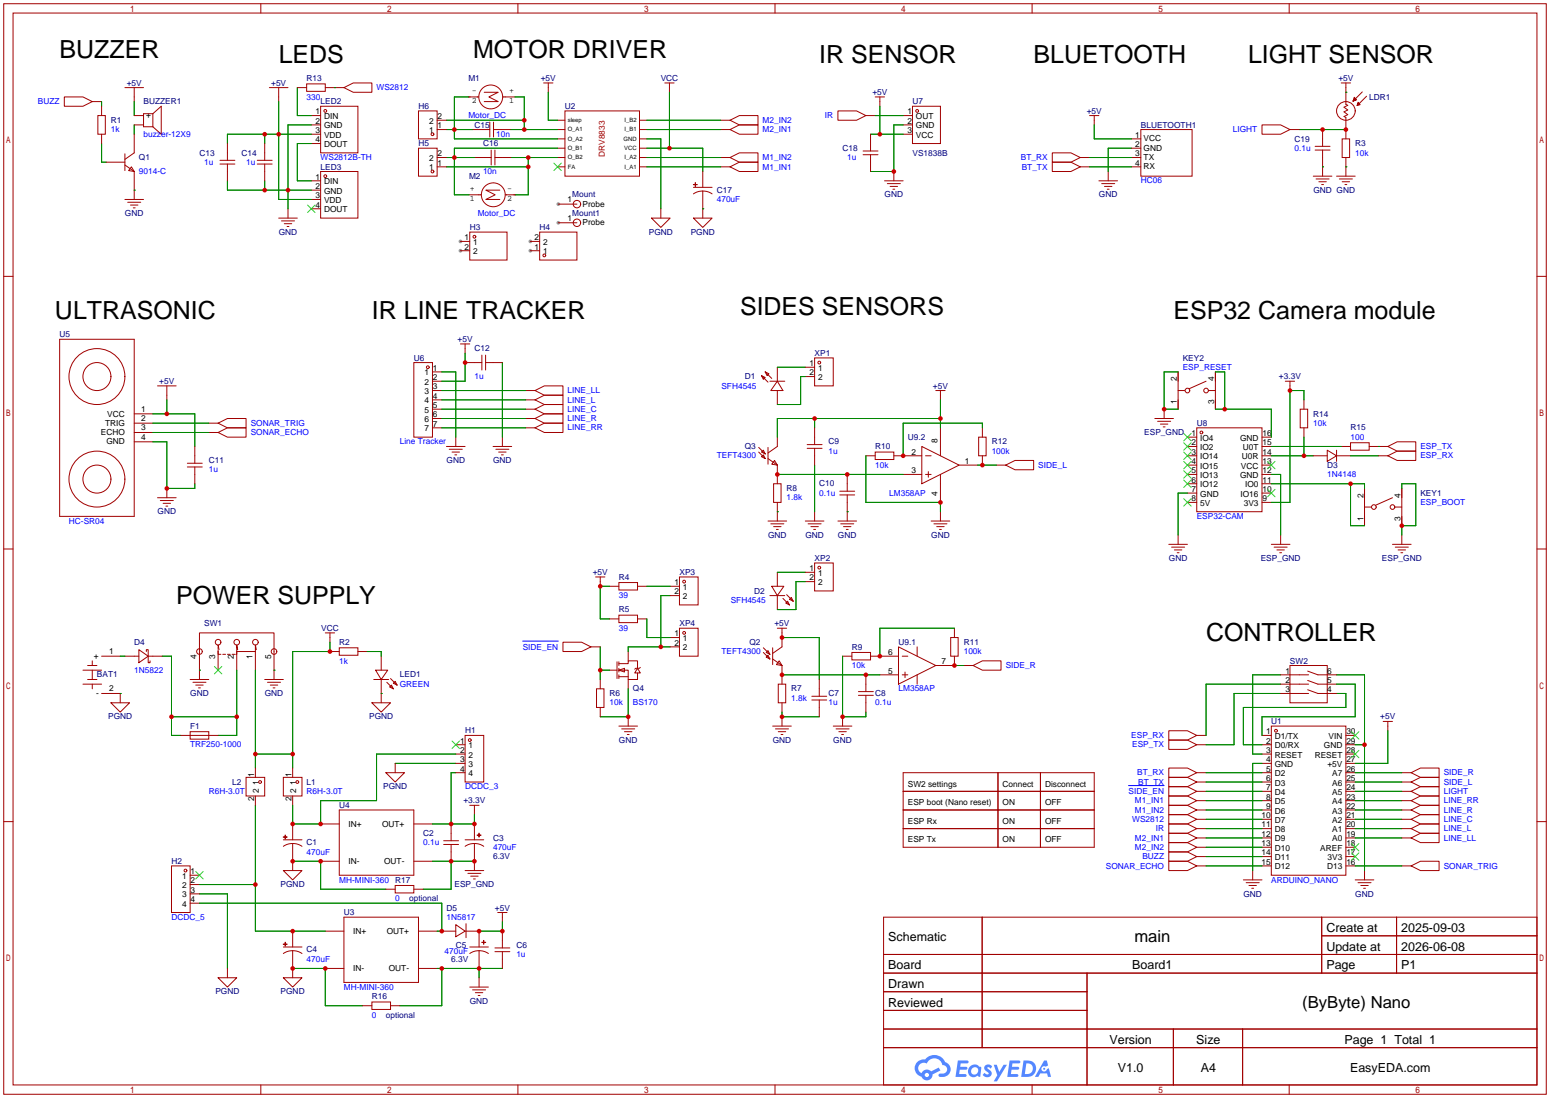
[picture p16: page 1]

SW2 settings | Connect | Disconnect
ESP boot (Nano reset) | ON | OFF

Update at | 2026-06-08

Board | Board1 | Page | P1
Drawn | | Бабай (ByByte) Nano
Reviewed

Version | Size | Page 1 Total 1
V1.0 | A4 | EasyEDA.com

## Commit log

2025-09-23 initial commit and add readme files
    [Drill_NPTH_Through.DRL, Drill_PTH_Through.DRL, Drill_PTH_Through_Via.DRL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]
2025-10-14 Fix mistakes and update design
    [Drill_NPTH_Through.DRL, Drill_PTH_Through.DRL, Drill_PTH_Through_Via.DRL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]
2026-05-25 update SCH, PCB, photos and generate BOM with images.
    [Drill_NPTH_Through.DRL, Drill_PTH_Through.DRL, Drill_PTH_Through_Via.DRL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]
2026-05-26 fix and extend BOM & fix and update PCB & CAD files to v.1.1
2026-06-03 update PCB to version 1.1
2026-06-09 update BOM and images
2026-06-09 update power rail and update BOM
2026-08-05 add 3D printed sensors shell
    [side-sensor-cover.step, side-sensor-cover.stl]
2026-09-06 update design and add 3D models
    [camera-holder.stl, clamp.stl, main-rail.stl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]

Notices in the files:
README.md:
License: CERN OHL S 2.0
